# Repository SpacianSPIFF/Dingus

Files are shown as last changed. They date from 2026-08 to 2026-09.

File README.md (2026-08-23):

# Dingus

The dignified turret.

A 2-DOF (yaw + pitch) turret that mimics the orientation of a handheld controller in real time. Tilt and rotate the controller, and the turret follows. Powered by an ESP32 + IMU on the controller side, talking wirelessly to an ESP32 on the turret side.

## Overview

- **Controller:** ESP32 + MPU6050 IMU + fire button. Reads raw IMU data, runs sensor fusion to estimate orientation, and streams pose + fire commands to the turret over Wi-Fi.
- **Turret:** ESP32 receives commands and drives yaw (servo), pitch (servo), a flywheel (brushless motor) for launching, a dart-push motor, and a reload-gear motor.

See `Docs/img/Controller_Side_Circuit.png` and `Docs/img/Turret_Side_Circuit.png` for the wiring block diagrams.

## Status

Work in progress. See [`Buildlog.md`](./Buildlog.md) for progress.

## Repo Structure

```text
Dingus/
├── CAD/                    # 15 parts — turret assembly + controller enclosure
├── Docs/
│   └── img/                # circuit diagrams + wiring photos
├── Firmware/
├── Buildlog.md
├── README.md
└── Testrig.pdf
```

## Setup & Running

> TODO: fill in once firmware is in a runnable state.

## Hardware

| Component | Role |
|---|---|
| ESP32 (x2) | Controller + Turret compute |
| MPU6050 | IMU for orientation sensing |
| RDS5160 Servo | Yaw |
| MG995 Servo | Pitch |
| Brushless Motor | Flywheel (launch) |
| DC Motor | Dart push |
| DC Motor | Reload gear |

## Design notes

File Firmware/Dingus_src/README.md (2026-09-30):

# Dingus Turret Firmware

A 2-DOF (yaw + pitch) turret aimed by a handheld, IMU-based orientation controller.
The controller is held in the hand; tilting and rotating it points the turret the
same way. Built for the RMI test-rig assignment (Turret Mechanism topic).

Two ESP32 boards talk over ESP-NOW:

- **controller** - reads an MPU6050 IMU, fuses it into a roll/pitch/yaw estimate,
  reads two buttons, drives a small OLED status display, and transmits a command
  packet ~50 times a second.
- **turret** - receives that packet, applies safety limits, and drives two servos
  (yaw, pitch) plus (eventually) a flywheel ESC and a dart-pusher servo.

Both are ESP-IDF projects, sharing a small common component for the wire protocol
and ESP-NOW bring-up.

---

## Repository layout

```
Dingus_src/
├── components/
│   └── turret_common/        # code shared by BOTH boards
│       ├── include/
│       │   ├── packet.h            # wire format for controller -> turret packets
│       │   └── espnow_common.h
│       └── espnow_common.c         # WiFi/ESP-NOW bring-up, identical either side
│
├── controller/                # ESP-IDF project #1 - the handheld unit
│   └── main/
│       ├── main.c                  # orchestration: ties every module below together
│       ├── i2c_bus.c/.h             # one shared I2C bus (MPU6050 + OLED both sit on it)
│       ├── imu_mpu6050.c/.h         # raw accel/gyro reads from the MPU6050
│       ├── gyro_cal.c/.h            # startup gyro bias calibration
│       ├── orientation.c/.h         # complementary filter -> roll/pitch/yaw
│       ├── buttons.c/.h             # debounced, edge-triggered fire + mode buttons
│       ├── oled.c/.h                # SSD1306 128x32 status display driver
│       └── espnow_send.c/.h         # packs orientation into a packet, sends it
│
└── turret/                    # ESP-IDF project #2 - the turret unit
    └── main/
        ├── main.c                  # orchestration: failsafe, limits, servo output
        ├── espnow_recv.c/.h         # receives packets, tracks link freshness
        └── servo.c/.h               # generic servo PWM driver (ledc-based)
```

Each of `controller/` and `turret/` is built and flashed independently
(`cd controller && idf.py build flash monitor`, same for `turret/`).
`components/turret_common/` is pulled into both via `EXTRA_COMPONENT_DIRS`.

---

## Design principle: modular, not tangled

Every file except each project's `main.c` is written to be usable on its own,
with no knowledge of the rest of the system:

- `imu_mpu6050.c` knows how to talk to an MPU6050 over I2C. It does not know the
  result will be fused into an orientation, displayed, or transmitted.
- `oled.c` knows how to draw text to a 128x32 SSD1306. It does not know what the
  text *means*.
- `orientation.c` knows how to fuse gyro + accel into an angle estimate. It does
  not know where the gyro data came from or what happens to its output.
- `servo.c` knows how to turn an angle into a PWM signal on a given GPIO. It does
  not know it's driving a "yaw axis" specifically.
- `espnow_recv.c` knows how to receive and timestamp packets. It does not know
  what a "yaw" or "pitch" field means, or that a servo exists.

`main.c` in each project is the only place that understands what the turret rig
*is* - it reads from these modules, applies the actual control logic (limits,
calibration sequencing, failsafe behavior), and writes to them. This means any
single piece (say, the IMU, or the display) could be dropped into an unrelated
project unchanged.

---

## The wire protocol - `packet.h`

```c
typedef struct __attribute__((packed)) {
    uint32_t seq;        // incrementing counter
    float    yaw_deg;    // commanded yaw, workspace-limited on the turret side
    float    pitch_deg;  // commanded pitch, workspace-limited on the turret side
    uint8_t  trigger;    // edge-triggered: 1 only on the packet sent at the
                          // instant the fire button was pressed, 0 otherwise
} turret_cmd_t;
```

This is the only thing the two boards agree on. `__attribute__((packed))` forces
an identical byte layout on both sides regardless of compiler padding decisions -
without it, the two boards could silently disagree on the struct's memory layout
and every field after the first would read as garbage.

`seq` isn't used for ordering - it exists so the turret can log/debug which
packet it's acting on. The actual staleness check (see Failsafe, below) is based
on wall-clock time of arrival, not the sequence number.

---

## Controller side, module by module

### `i2c_bus.c/.h`
Creates a single I2C bus on the default pins (SDA=GPIO21, SCL=GPIO22). Both the
MPU6050 and the OLED are I2C devices at different addresses (`0x68` and `0x3C`)
and share this one bus - created once in `main.c`, handed to both device drivers.

### `imu_mpu6050.c/.h`
Wakes the MPU6050 from its power-on sleep state, configures ±2g / ±250°/s full
scale ranges, and exposes `mpu6050_read()` which returns raw accelerometer (g)
and gyroscope (deg/s) values. No filtering, no calibration - that's layered on
top by other modules.

### `gyro_cal.c/.h`
Runs once at boot, before the main loop starts. Samples the gyro for ~3 seconds
(the controller must be held still) and averages the result into a per-axis
bias. This bias is subtracted from every gyro reading from then on, which is
what prevents the yaw/roll/pitch estimate from drifting due to the gyro's
inherent zero-rate offset. Reports progress via a callback so the display module
never needs to know calibration exists.

### `orientation.c/.h`
A complementary filter: each axis is (mostly) the gyro reading integrated over
time, continuously pulled back toward whatever the accelerometer implies, at a
98%/2% blend. This corrects gyro drift on **roll and pitch**, because gravity
gives the accelerometer an absolute reference for those two axes. **Yaw has no
such reference** (rotating around the vertical axis doesn't change what gravity
looks like to the sensor) - without a magnetometer, yaw is pure integration and
will drift over time. This is a known, accepted limitation, mitigated by:

- A long-press (>1s) on the mode button calls `orientation_zero_yaw()`, letting
  the operator re-center yaw whenever drift becomes noticeable.

### `buttons.c/.h`
Two GPIOs (fire = GPIO4, mode = GPIO5), configured with internal pull-ups, read
as active-low. Exposes simple debounced, edge-triggered `button_*_pressed()`
functions - each returns `true` exactly once per physical press, not once per
loop iteration the button happens to be held down. The long-press-to-zero-yaw
gesture is currently detected separately, directly in `main.c`, since it needs
duration rather than a single edge event.

### `oled.c/.h`
A from-scratch SSD1306 128x32 driver: a 512-byte framebuffer, a hand-rolled 5x7
bitmap font, and I2C writes to push the buffer to the display. Exposes
`oled_draw_text(x, y, string)` - the caller decides what the text says; this
file only knows how to put pixels on the glass.

### `espnow_send.c/.h`
Registers the turret's MAC address as an ESP-NOW peer and exposes
`espnow_send_cmd()`, which fires a `turret_cmd_t` off over the air. Nothing more
- packing the struct with real orientation/trigger data happens in `main.c`.

### `main.c`
Boot sequence: bring up ESP-NOW → I2C bus → IMU → OLED → buttons → gyro
calibration (with a live percentage shown on-screen) → then the main ~50Hz loop:

1. Poll the mode button for a tap (toggle ORIENT/MANUAL) or a long-press (zero yaw).
2. Poll the fire button (edge-triggered).
3. Read the IMU, subtract calibration bias from the gyro values.
4. Run the complementary filter to update roll/pitch/yaw.
5. Pack yaw/pitch/trigger into a `turret_cmd_t` and send it.
6. Draw the current mode, roll/pitch/yaw, and a "FIRE" flash (held briefly so
   it's actually visible, since the underlying button press is only a single
   loop iteration long) to the OLED.

---

## Turret side, module by module

### `espnow_recv.c/.h`
Registers a receive callback for incoming ESP-NOW packets. Every time one
arrives, it's copied into a local "latest command" and timestamped. Exposes:

- `espnow_recv_get_latest()` - the most recent command received, if any.
- `espnow_recv_link_alive()` - `true` only if a packet has arrived within the
  last 500ms. This is the **failsafe** the brief requires: if the link drops,
  this flips to `false`, and `main.c` uses that to freeze the turret in place.

This module doesn't currently filter by sender MAC address - it will accept a
well-formed packet from anything broadcasting to it. Fine for a closed two-device
system; worth tightening if that assumption ever changes.

### `servo.c/.h`
A generic hobby-servo PWM driver built on the ESP32's `ledc` peripheral. One
shared 50Hz timer drives multiple independent channels (one per physical servo).
`servo_set_angle()` maps a 0–180° angle to a 500–2500µs pulse width - the
standard range confirmed against both the RDS5160 and MG946R datasheets - and
writes the corresponding PWM duty cycle. Clamps to 0–180° as a hard safety net;
the *real*, narrower workspace limits (see below) are applied one layer up.

### `main.c`
Boot sequence: bring up ESP-NOW receive → configure the shared servo timer →
init the yaw servo (GPIO18) and pitch servo (GPIO19). Then the main ~50Hz loop:

1. Pull the latest received command and check whether the link is still alive.
2. **If the link is dead, or nothing has ever arrived: do nothing.** The servos
   are simply never told to move, so they hold their last commanded position -
   satisfying the "hold last position and refuse to launch until the link is
   restored" requirement directly, rather than as a bolted-on special case.
3. Otherwise:
   - Clamp the commanded yaw to **±90°** and pitch to **0–60°** (the defined
     workspace from the brief).
   - Convert to servo-relative degrees (yaw is remapped from the controller's
     −90..+90 convention to the servo's 0..180 convention around its mechanical
     center).
   - Apply a **deadband** (ignore changes smaller than 0.5°, so sensor noise
     doesn't make the servo hunt) and a **slew-rate limit** (cap how many
     degrees the commanded angle may change per loop iteration, so the turret
     moves smoothly rather than snapping).
   - Write the resulting angles to both servos.
   - If `trigger` is set, fire - currently a placeholder log line, pending the
     actual firing-mechanism hardware and its GPIO.

---

## Known limitations / things still to do

- **Yaw drift** is expected and understood, not a bug - see the `orientation.c`
  section above. Mitigated by the long-press re-center gesture.
- **No sender authentication** on the turret's ESP-NOW receive - see
  `espnow_recv.c/.h` above.
- **Accelerometer validity isn't checked before blending** - a hard shake or
  free-fall would momentarily corrupt the roll/pitch estimate, since the filter
  currently assumes the accelerometer always reads ~1g of gravity. Not an issue
  for normal handheld aiming; worth revisiting if roll/pitch ever glitch during
  fast motion.
- **Firing mechanism** is not yet wired - `turret/main.c` logs the intent to
  fire but does not yet trigger any hardware.
- **Manual mode** (the second button's alternate mode) is tracked as a state but
  has no distinct behavior implemented yet.
- **Homing on boot**, **ballistic aim-assist**, and **telemetry streaming** are
  stretch objectives from the brief, not yet started.

---

## Building

```bash
cd controller && idf.py build flash monitor    # handheld unit
cd turret     && idf.py build flash monitor   # turret unit
```

Each project is independent - `idf.py` must be run from inside `controller/` or
`turret/`, never from the repository root.

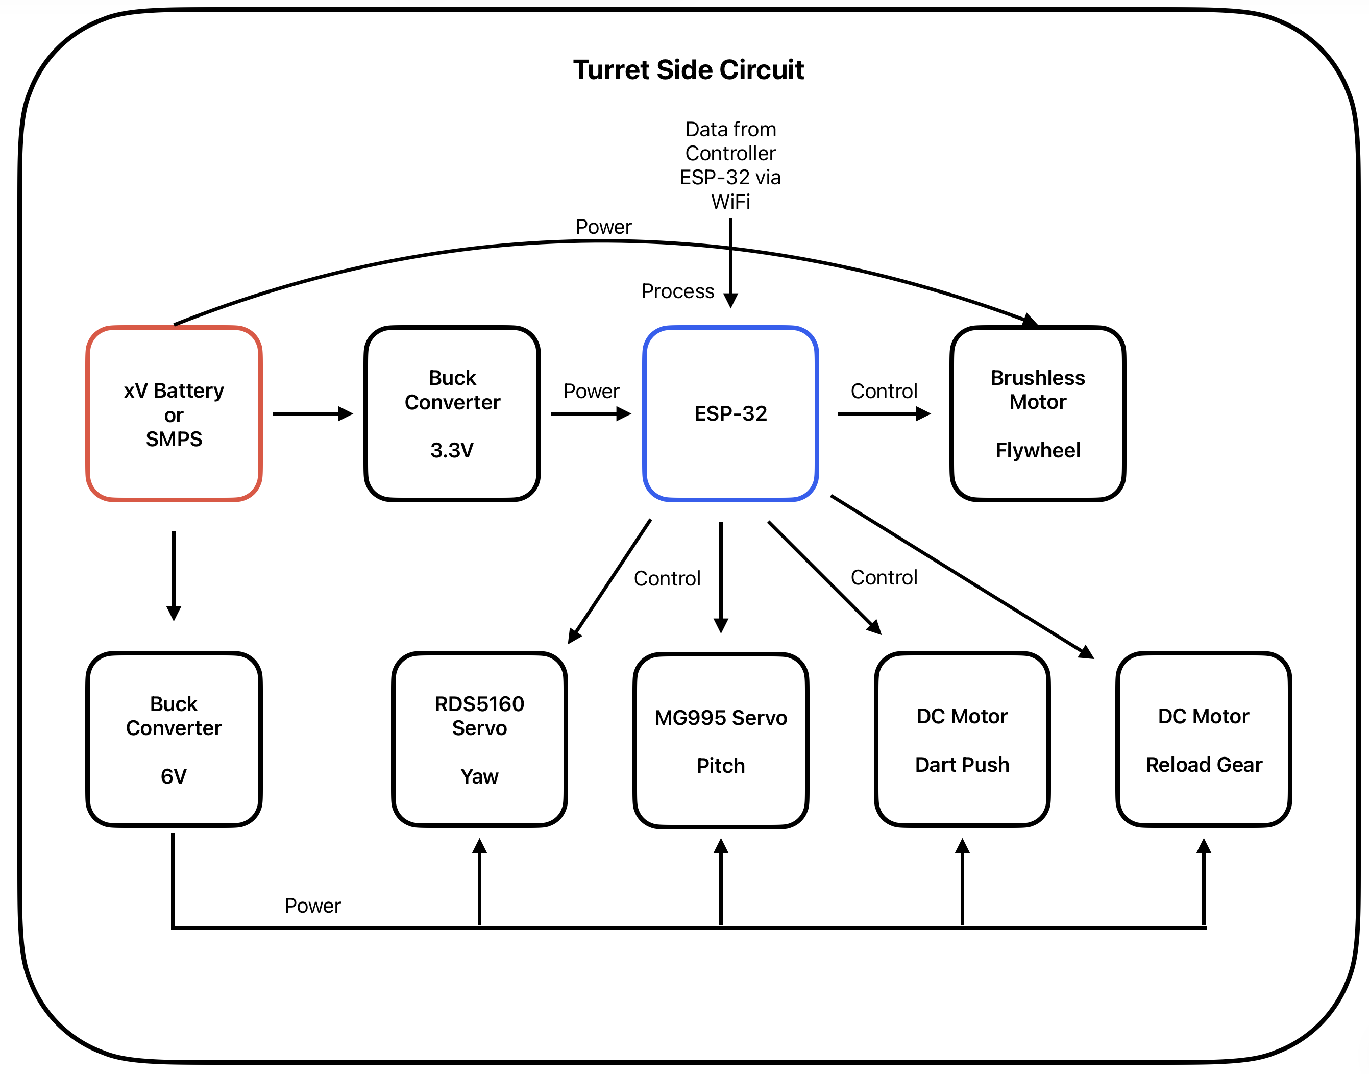
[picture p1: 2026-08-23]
Docs/img/Turret_Side_Circuit.png

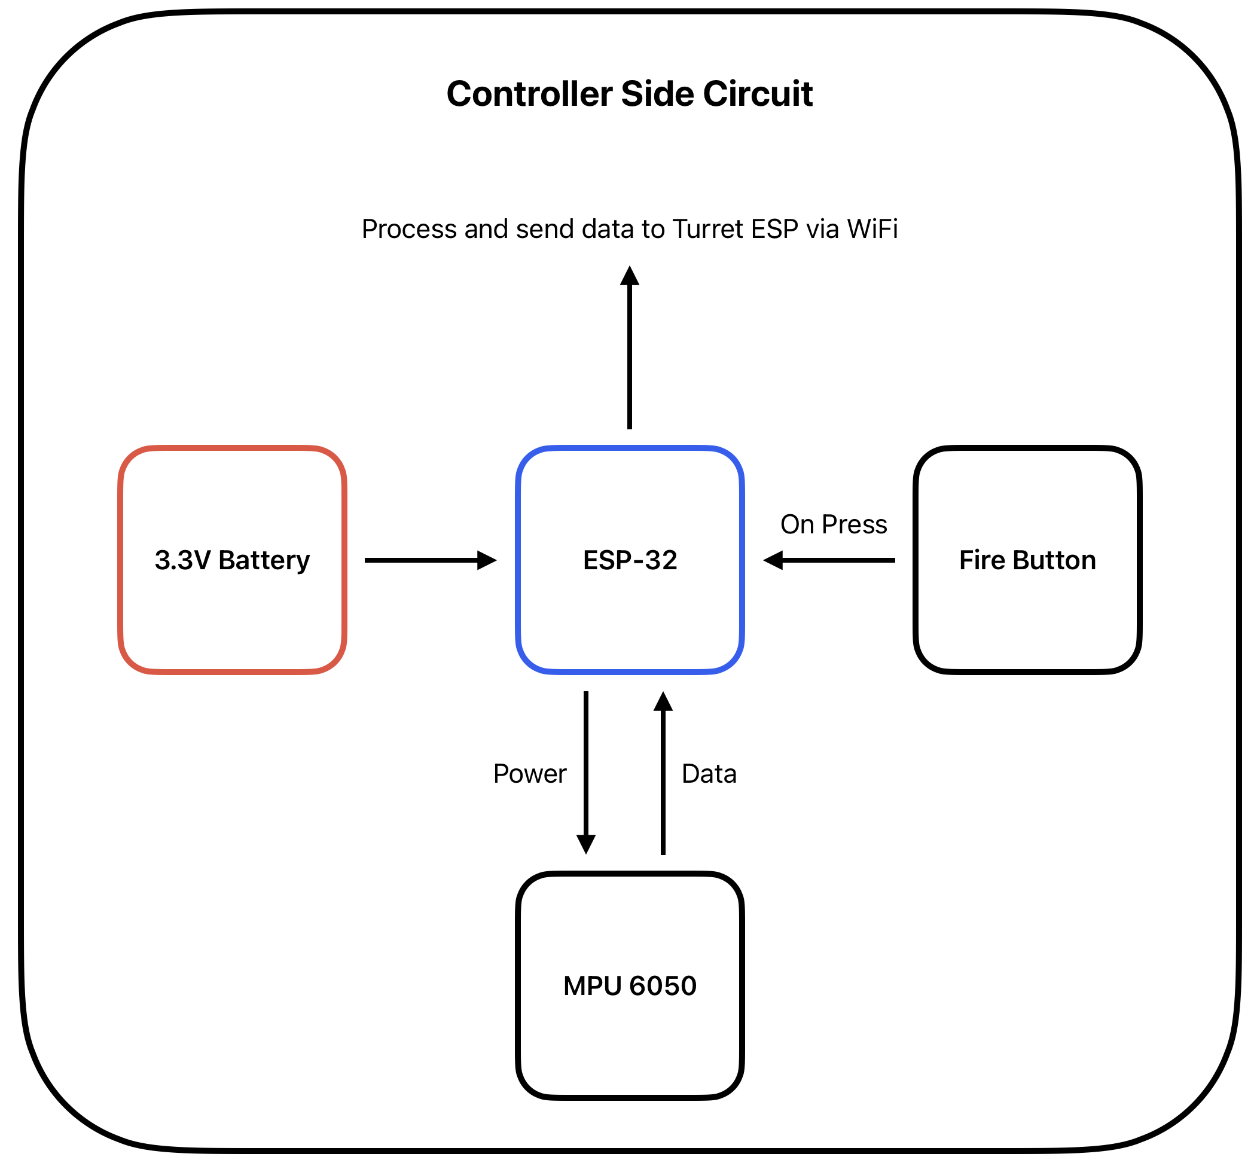
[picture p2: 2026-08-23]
Docs/img/Controller_Side_Circuit.png

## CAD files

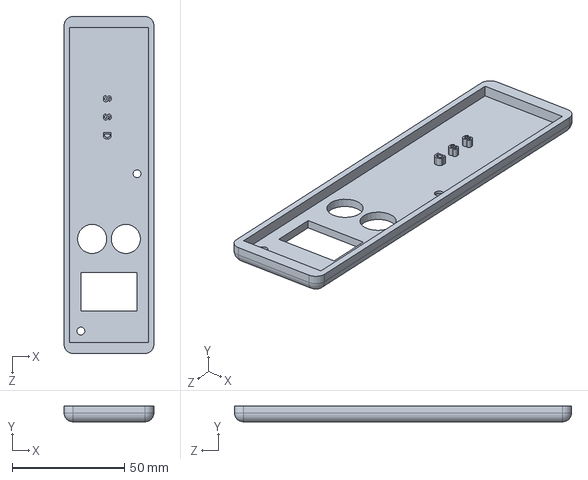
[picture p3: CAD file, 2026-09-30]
CAD/Controller/Controller Top.SLDPRT
40.0 x 7.00 x 150.0 mm

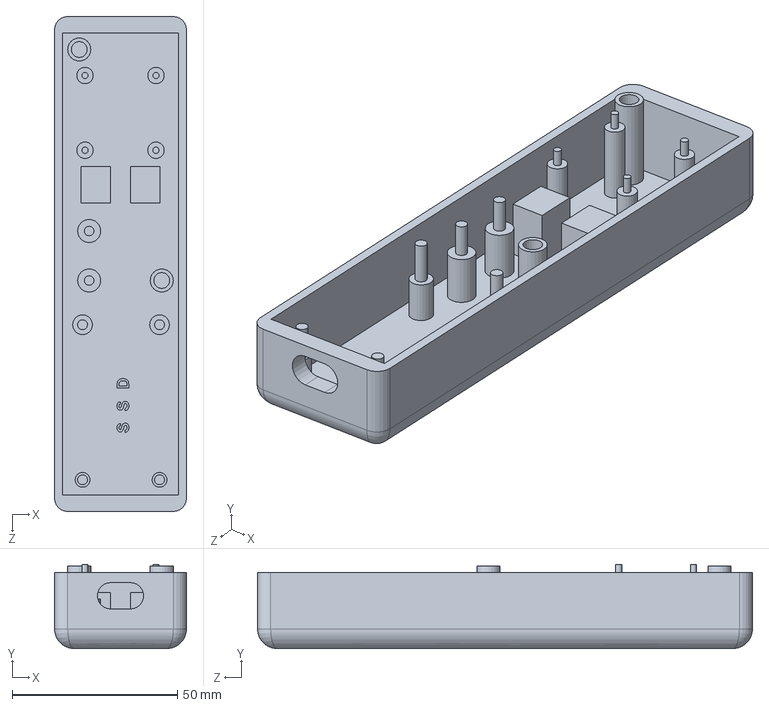
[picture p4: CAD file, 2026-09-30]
CAD/Controller/Controller Base.SLDPRT
40.0 x 25.5 x 150.0 mm

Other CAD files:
CAD/Turret/Dart.f3d
CAD/Turret/Firing Nozzle.f3d
CAD/Turret/Flywheel Base.f3d
CAD/Turret/Flywheel.f3d
CAD/Turret/Reload Gear.f3d

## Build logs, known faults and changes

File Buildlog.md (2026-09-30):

# Build Log

## 2026-09-30

**Focus:** Maximise progress

**Summary:**
- The Mode change and Yaw calibrate button doesn't work, not sure why. Yaw calibrate basically being that the yaw shoots off randomly overtime, which it shouldn't, and so to fix that if one holds the button, it resets yaw to 0
- Fixed code bug where the Roll and Pitch is swapped

## 2026-09-29

**Focus:** Finishing of the code and model

**Summary:**
- Finally got the controller packaged, and flashed. Looks like the ["Finishing the controller"](#2026-09-23) never actually finished... But fine, got it done now
- Well, I finished _almost_ the entire code today... (yes, I used AI, but it's fine for now)
- Put parts to print, but turns out many flaws in modelling, like the dimensions, and the further mount planning, so gotta redo
- Started soldering the perfboard for the turret

## 2026-09-28

**Focus:** Writing code for the controller

**Summary:**
- Finished wiring the controller, though many times a loose conneciton makes the ESP reset by itself, for I believe something is pulling a bus low. Now for that I need to now figure out how to fix a perfboard in the _severly_ limited volume of the controller, as i designed it without a perfboard in mind... Maybe I can reprint it without the standoffs?
- Wrote significant portion of the code for the controller
- Tested th ecode currently wrote... Builds and displays on the OLED also
- Next up is the ESP-NOW and the turret code left
- I have been putting off the modelling for way too long for the turret. hae to finish that ASAP

## 2026-09-23

**Focus:** Finishing the controller

**Summary:**
- Finished the CAD model and printing of the controller
- The base had many issues, fixed them one by one, primarily being the dimensions
- Started wiring the electronics on the controller

## 2026-09-19

**Focus:** Move modelling to Solidworks, and finish off the controller. Also initialising the code base

**Timeline:** Majorly the previous week

**Summary:**
- Well, I restarted modelling everything from scratch in Solidworks, as RMI prmiarily works on it, and not Fusion.
- So I primarily worked on modelling the controller. Thinking about how I should design it. Initially my idea was to make it like the [Nintendo Wii's Nunchuk](https://nintendo.fandom.com/wiki/Nunchuk), But figuring out the component placement + complexity made me reconsider, and I moved to a much simpler TV remote style. So initially my idea was to go completely screwless for the controller, making it look aesthetic, but then when I tried *press fit* with different tolerances, it just wouldn't work. Later while assembly I realised the sheer blunder I commited, while not taking into account on how to even place the components, and so, came the idea of standoffs, where each component would sit on these standoffs, and have enough space on the bottom for wires to go through, and so each components' height can be individually adjusted.
- I also initialised the code base for ESP-IDF, and under 1 project of ESP-IDF (that's how it considers?), I made like 2 projects in them? One for the controller, and one for the turret. They share the same communication protocol to send data via ESP-NOW, so a common `protocol.h` exists, just to ensure that happens. I'm yet to start full fledged programming, but yeah, the basic setup has been done for it, and I made sure to update the `CMakeLists.txt` files.
- And yes, finally understood that buil-logs are just putting down how we failed and progressed, so finally doing that :P
- Though one concern does exist, where my assemblies are touching 10-12MB each, and git storing binaries would just inflate the `.git` folder...? I don't know. Let's see.
- Oh also, just changed the folder structure a bit (I might keep doing that till I satisfy myself)
- I think I should maybe update the `README.md` file also soon.
- P. S. Been a while, but it's good to be back :)

## 2026-08-23

**Focus:** Continued modelling, and started electronic design

**Summary:**
- Made the circuit block diagrams
- Made CAD model for Reload Gear

## 2026-08-22

**Focus:** Finalised on the firing mechanism, and started modelling

**Summary:**
- Made CAD models for:
  - Dart
  - Firing Nozzle
  - Flywheel Base
  - Flywheel

## 2026-08-21

**Focus:** Ideation for firing mechanism for the turret

**Summary:**
- Was able to come up with 3 methods of firing:
  1. High speed fly wheel with a dart pusher + dart loader mechanism with grooved gears. A variant of it can also be done for beads, where the gear has dimples on it instead of grooves.
  2. Use a spring with a plate in front of it to launch the bead. The plate has a hook, with thread tied to it, which connects on one side of ratchet and pawl mechanism, and the other side of it is connected to a motor, which enables free flow of the spring in one direction, and helps pull the spring back in the other direction.
  3. In the first mechanism itself, if a bead is kept, once it is loaded, instead of flywheel, use a paddle to hit the bead at high speed, like a pinball paddle.

## 2026-08-14

**Focus:** Thought of the entire design of the turret

**Summary:**
- Initialised GitHub repo
- Set up basic project structure

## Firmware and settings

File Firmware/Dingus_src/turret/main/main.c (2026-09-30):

#include <stdio.h>
#include <math.h>
#include "freertos/FreeRTOS.h"
#include "freertos/task.h"
#include "espnow_common.h"
#include "espnow_recv.h"
#include "packet.h"
#include "servo.h"

// Limits for the angles
#define YAW_MIN_DEG    -90.0f
#define YAW_MAX_DEG     90.0f
#define PITCH_MIN_DEG   0.0f
#define PITCH_MAX_DEG   60.0f

// Deadband: ignore commanded changes smaller than this (sensor noise floor)
#define DEADBAND_DEG    0.5f

// Slew rate: max degrees the commanded angle may change per loop iteration
#define SLEW_RATE_DEG_PER_LOOP  2.0f

#define YAW_GPIO    18
#define PITCH_GPIO  19

static float clampf(float v, float lo, float hi)
{
    if (v < lo) return lo;
    if (v > hi) return hi;
    return v;
}

// Applies deadband + slew-rate limiting. current is updated in place.
static float slew_towards(float current, float target, float max_step)
{
    float diff = target - current;
    if (fabsf(diff) < DEADBAND_DEG) return current;  // inside deadband, hold
    if (diff > max_step) diff = max_step;
    if (diff < -max_step) diff = -max_step;
    return current + diff;
}

void app_main(void)
{
    ESP_ERROR_CHECK(espnow_common_init());
    ESP_ERROR_CHECK(espnow_recv_init());

    ESP_ERROR_CHECK(servo_timer_init());
    servo_t yaw_servo, pitch_servo;
    ESP_ERROR_CHECK(servo_init(&yaw_servo, LEDC_CHANNEL_0, YAW_GPIO));
    ESP_ERROR_CHECK(servo_init(&pitch_servo, LEDC_CHANNEL_1, PITCH_GPIO));

    // Servo angle convention: 90 = center. Yaw workspace -90..90 maps to servo 0..180.
    // Pitch workspace 0..60 maps directly (already servo-relative).
    float current_yaw_servo_deg = 90.0f;    // center
    float current_pitch_servo_deg = 0.0f;   // level

    while (1) {
        turret_cmd_t cmd;
        bool have_cmd = espnow_recv_get_latest(&cmd);
        bool link_ok = espnow_recv_link_alive();

        if (have_cmd && link_ok) {
            // Clamp commanded angles to workspace
            float target_yaw = clampf(cmd.yaw_deg, YAW_MIN_DEG, YAW_MAX_DEG);
            float target_pitch = clampf(cmd.pitch_deg, PITCH_MIN_DEG, PITCH_MAX_DEG);

            // Convert to servo-relative degrees (yaw: -90..90 -> 0..180)
            float target_yaw_servo = target_yaw + 90.0f;
            float target_pitch_servo = target_pitch;

            current_yaw_servo_deg = slew_towards(current_yaw_servo_deg, target_yaw_servo, SLEW_RATE_DEG_PER_LOOP);
            current_pitch_servo_deg = slew_towards(current_pitch_servo_deg, target_pitch_servo, SLEW_RATE_DEG_PER_LOOP);

            servo_set_angle(&yaw_servo, current_yaw_servo_deg);
            servo_set_angle(&pitch_servo, current_pitch_servo_deg);

            // Fire handling: only allowed when link is fresh
            if (cmd.trigger) {
                printf("FIRE (seq=%lu)\n", (unsigned long)cmd.seq);
                // actual firing mechanism trigger goes here once that hardware exists
            }
        } else {
            // No fresh command / link dead: HOLD last position, do not move servos,
            // and do not fire. current_yaw_servo_deg / current_pitch_servo_deg are
            // simply not updated, so servos stay exactly where they were.
            if (!link_ok && have_cmd) {
                printf("LINK LOST - holding position\n");
            }
        }

        vTaskDelay(pdMS_TO_TICKS(20));  // ~50Hz, matches controller's send rate
    }
}

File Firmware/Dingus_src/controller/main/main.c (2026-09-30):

#include <stdio.h>
#include "freertos/FreeRTOS.h"
#include "freertos/task.h"
#include "esp_timer.h"
#include "driver/gpio.h"
#include "i2c_bus.h"
#include "imu_mpu6050.h"
#include "oled.h"
#include "buttons.h"
#include "gyro_cal.h"
#include "orientation.h"
#include "espnow_send.h"
#include "espnow_common.h"
#include "packet.h"

typedef enum { MODE_ORIENT, MODE_MANUAL } controller_mode_t;

static void cal_progress_cb(int percent)
{
    oled_clear();
    oled_draw_text(0, 0, "CALIBRATING");
    oled_draw_text(0, 1, "HOLD STILL");
    char pct[16];
    snprintf(pct, sizeof(pct), "%d%%", percent);
    oled_draw_text(0, 2, pct);
    oled_flush();
}

// Long-press detection for the mode button, layered on top of buttons.c's
// edge-triggered button_mode_pressed(). We track how long GPIO stays low
// ourselves here, separate from the debounced edge logic, since we need
// duration rather than just a press event.
#define LONG_PRESS_MS 1000

static bool mode_btn_was_down = false;
static int64_t mode_btn_down_since_us = 0;
static bool mode_long_press_fired = false;

typedef enum { MODE_ACTION_NONE, MODE_ACTION_TOGGLE, MODE_ACTION_ZERO_YAW } mode_action_t;

static mode_action_t poll_mode_button_action(void)
{
    bool level_low = gpio_get_level(BUTTON_MODE_GPIO) == 0;  // pressed = low
    int64_t now_us = esp_timer_get_time();

    if (level_low && !mode_btn_was_down) {
        mode_btn_was_down = true;
        mode_btn_down_since_us = now_us;
        mode_long_press_fired = false;
    } else if (level_low && mode_btn_was_down) {
        if (!mode_long_press_fired &&
            (now_us - mode_btn_down_since_us) >= LONG_PRESS_MS * 1000) {
            mode_long_press_fired = true;
            return MODE_ACTION_ZERO_YAW;
        }
    } else if (!level_low && mode_btn_was_down) {
        mode_btn_was_down = false;
        bool was_long = mode_long_press_fired;
        mode_long_press_fired = false;
        if (!was_long) {
            return MODE_ACTION_TOGGLE;
        }
    }

    return MODE_ACTION_NONE;
}

void app_main(void)
{
    ESP_ERROR_CHECK(espnow_common_init());

    i2c_master_bus_handle_t bus;
    ESP_ERROR_CHECK(i2c_bus_init(&bus));
    ESP_ERROR_CHECK(mpu6050_init(bus));
    ESP_ERROR_CHECK(oled_init(bus));
    buttons_init();
    ESP_ERROR_CHECK(espnow_send_init());

    gyro_bias_t bias = {0};
    ESP_ERROR_CHECK(gyro_calibrate(&bias, cal_progress_cb));

    oled_clear();
    oled_draw_text(0, 0, "CAL DONE");
    oled_flush();
    vTaskDelay(pdMS_TO_TICKS(500));

    int64_t fire_display_until_us = 0;
    #define FIRE_DISPLAY_HOLD_MS 500

    orientation_t orient;
    orientation_init(&orient);

    controller_mode_t mode = MODE_ORIENT;
    mpu6050_data_t imu;
    uint32_t seq = 0;

    while (1) {
        mode_action_t action = poll_mode_button_action();
        if (action == MODE_ACTION_TOGGLE) {
            mode = (mode == MODE_ORIENT) ? MODE_MANUAL : MODE_ORIENT;
        } else if (action == MODE_ACTION_ZERO_YAW) {
            orientation_zero_yaw(&orient);
        }

        bool fired = button_fire_pressed();
        if (fired) {
            fire_display_until_us = esp_timer_get_time() + (FIRE_DISPLAY_HOLD_MS * 1000);
        }
        bool show_fire_text = esp_timer_get_time() < fire_display_until_us;

        mpu6050_read(&imu);
        float gx = imu.gyro_x - bias.gyro_x;
        float gy = imu.gyro_y - bias.gyro_y;
        float gz = imu.gyro_z - bias.gyro_z;
        orientation_update(&orient, gx, gy, gz, imu.accel_x, imu.accel_y, imu.accel_z);

        // Workspace clamping (±90 yaw, 0-60 pitch), deadband, and slew-rate limiting
        // are NOT applied yet — will be added once raw transmission is confirmed.
        turret_cmd_t cmd = {
            .seq = seq++,
            .yaw_deg = orient.yaw_deg,
            .pitch_deg = orient.pitch_deg,
            .trigger = fired ? 1 : 0,
        };
        espnow_send_cmd(&cmd);

        oled_clear();
        oled_draw_text(0, 0, mode == MODE_ORIENT ? "MODE ORIENT" : "MODE MANUAL");
        char line[24];
        snprintf(line, sizeof(line), "R%d P%d Y%d",
                 (int)orient.roll_deg, (int)orient.pitch_deg, (int)orient.yaw_deg);
        oled_draw_text(0, 1, line);
        oled_draw_text(0, 2, show_fire_text ? "*** FIRE ***" : "");
        oled_flush();

        vTaskDelay(pdMS_TO_TICKS(20));
    }
}

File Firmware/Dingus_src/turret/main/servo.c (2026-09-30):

#include "servo.h"
#include "esp_log.h"
#include <math.h>

static const char *TAG = "servo";

esp_err_t servo_timer_init(void)
{
    ledc_timer_config_t timer_cfg = {
        .speed_mode = LEDC_LOW_SPEED_MODE,
        .duty_resolution = SERVO_PWM_RESOLUTION,
        .timer_num = LEDC_TIMER_0,
        .freq_hz = SERVO_PWM_FREQ_HZ,
        .clk_cfg = LEDC_AUTO_CLK,
    };
    esp_err_t err = ledc_timer_config(&timer_cfg);
    if (err != ESP_OK) {
        ESP_LOGE(TAG, "timer_config failed: %s", esp_err_to_name(err));
    }
    return err;
}

esp_err_t servo_init(servo_t *servo, ledc_channel_t channel, int gpio)
{
    servo->channel = channel;
    servo->gpio = gpio;

    ledc_channel_config_t ch_cfg = {
        .speed_mode = LEDC_LOW_SPEED_MODE,
        .channel = channel,
        .timer_sel = LEDC_TIMER_0,
        .intr_type = LEDC_INTR_DISABLE,
        .gpio_num = gpio,
        .duty = 0,
        .hpoint = 0,
    };
    esp_err_t err = ledc_channel_config(&ch_cfg);
    if (err != ESP_OK) {
        ESP_LOGE(TAG, "channel_config failed on GPIO%d: %s", gpio, esp_err_to_name(err));
    }
    return err;
}

void servo_set_angle(const servo_t *servo, float angle_deg)
{
    if (angle_deg < SERVO_ANGLE_MIN) angle_deg = SERVO_ANGLE_MIN;
    if (angle_deg > SERVO_ANGLE_MAX) angle_deg = SERVO_ANGLE_MAX;

    // Map angle -> pulse width (us) -> duty cycle counts
    float pulse_us = SERVO_PULSE_MIN_US +
        (angle_deg / SERVO_ANGLE_MAX) * (SERVO_PULSE_MAX_US - SERVO_PULSE_MIN_US);

    uint32_t max_duty = (1 << SERVO_PWM_RESOLUTION) - 1;
    float period_us = 1000000.0f / SERVO_PWM_FREQ_HZ;  // 20000us at 50Hz
    uint32_t duty = (uint32_t)((pulse_us / period_us) * max_duty);

    ledc_set_duty(LEDC_LOW_SPEED_MODE, servo->channel, duty);
    ledc_update_duty(LEDC_LOW_SPEED_MODE, servo->channel);
}

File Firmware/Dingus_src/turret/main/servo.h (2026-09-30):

#pragma once
#include <stdint.h>
#include "esp_err.h"
#include "driver/ledc.h"

// Standard hobby servo pulse range — verified against RDS5160 and MG946R datasheets.
// Trim per-servo if real hardware buzzes/strains at either extreme.
#define SERVO_PULSE_MIN_US 500
#define SERVO_PULSE_MAX_US 2500
#define SERVO_ANGLE_MIN    0
#define SERVO_ANGLE_MAX    180

#define SERVO_PWM_FREQ_HZ     50
#define SERVO_PWM_RESOLUTION  LEDC_TIMER_14_BIT  // 16384 steps — plenty of resolution at 50Hz

typedef struct {
    ledc_channel_t channel;
    int gpio;
} servo_t;

// Initializes the shared LEDC timer (call once) and configures one servo's channel.
esp_err_t servo_timer_init(void);
esp_err_t servo_init(servo_t *servo, ledc_channel_t channel, int gpio);

// angle_deg: 0-180, clamped internally to SERVO_ANGLE_MIN/MAX.
void servo_set_angle(const servo_t *servo, float angle_deg);

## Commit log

2026-08-23 Updated docs and added CAD files
    Made a basic README.md, and wrote in Buildlog.md. Few CAD files regarding the firing system has been also added. Along with it, the preliminary circuit block diagram images have been added.
    [Dart.f3d, Firing Nozzle.f3d, Flywheel Base.f3d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]
2026-09-18 Switch to SolidWorks and Initialise the code base
    Remodelled everything again in SolidWorks and then continued,
    primarily the controller.
    - Also initialised the code base for ESP-IDF having 2 projects in one?
    - Restructured the folder structure.
    - Will commit the final models for controller after finishing.
    - Turret is still being modelled.
    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
    [Dart.f3d, Firing Nozzle.f3d, Flywheel Base.f3d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]
2026-09-30 Add turret code
    [Controller Base.SLDPRT, Controller Top.SLDPRT]
2026-10-09 Add CAD and major code additions
    - Add turret all parts and assembly
    - Add controller assembly along with supporting components
    - Fixed code and added other useful changes
2026-10-10 Updated controller UI and turret servos
